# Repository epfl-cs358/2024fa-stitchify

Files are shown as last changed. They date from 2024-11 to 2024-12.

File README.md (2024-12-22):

<!-- ABOUT THE PROJECT -->

## Authors

Wiktoria Rozkosz, Bogdan Cîrje, Imane Raihane, Lorie Xu, Yasmine Hidri, Victor Zablocki

## About The Project
Fueled by curiosity, we worked to create a knitting machine from start to finish. The Knitting Robot is an Arduino-based automation system designed to knit simple fabric patterns such as scarves or scalable fabrics. The project aims to create a functional prototype capable of knitting patterns autonomously.

We based our work on the open source project OpenKnit, and spent a lot of time analysing and researching about how to go about in creating our machine. We obviously didn't have 5-6 years like OpenKnit did, so we had to simplify OpenKnit's design by a lot in order to fit the time frame of 10 weeks.

This is our project prototype in motion:
https://github.com/user-attachments/assets/023492ee-7dcc-4365-b6ac-0f5af49786ec

## Key Features
* **Web Interface**: A web app allows users to upload knitting patterns and customize their projects (e.g., scarves, beanies, or pullovers).
* **Real-Time Feedback**: An LCD screen on the knitting robot shows the progress and alerts users to any errors during operation.
* **Modular Design**: The system is designed to be modular, allowing future expansions and adaptations for more complex knitting patterns.
* **Educational Potential**: This project serves as a tool for teaching robotics, automation, and programming concepts.

## How It Works
The knitting robot operates by using a combination of stepper motors, actuators, and precision-controlled components to manipulate needles and yarn. The process is divided into the following key steps:
### 1. Pattern Upload:
* The user uploads a knitting pattern through the web interface. Typically, this pattern is a custom, text-based file that describes the sequence of knitting actions required for the design.
### 2. Conversion to Instructions:
* The uploaded pattern is then parsed and converted into a series of detailed instructions. These instructions control the robot’s movement and actions, dictating how needles should be raised or lowered.
* The system ensures precise execution of the pattern, coordinating between the needles, yarn feeder, and other actuators.
### 3. Knitting Process:
* Needle Movement: The carriage moves one needle at a time, enabling precise control over which needles are raised. Small servos embedded in the carriage allow the user to select individual needles for activation, ensuring each stitch is placed according to the pattern.
* Yarn Feeding: A large servo controls the yarn feeder, which performs a swiping motion to ensure accurate placement of the yarn on the needles. This motion enhances precision, especially at the endpoints, that require fine control over yarn tension and placement.
* Carriage Movement: The entire carriage is moved by a belt system powered by a NEMA stepper motor, ensuring smooth, coordinated motion across the entire width of the knitting surface.
### 4. Real-Time Feedback:
* LCD Screen: The system features an LCD screen that displays the progress of the knitting process, providing real-time feedback on the pattern's completion.
### 5. User Interaction:
* User Button: A dedicated button allows the user to pause or stop the machine after each row and confirm whether everything is functioning correctly. This button can be used to provide manual intervention if needed, ensuring the process runs smoothly.
### 6. Safety Features:
* Endpoint Switches: At the endpoints of the carriage, there are limit switches that prevent the system from overextending or damaging itself. These switches stop the carriage when it reaches the end of its travel, ensuring safe operation.
This combination of precise needle control, enhanced yarn feeding mechanisms, and real-time monitoring allows the knitting robot to produce high-quality knitting patterns with minimal manual intervention.

## Used Components

### Yarn Types:
- **Heavy Yarn**  
- **Normal Yarn**  
- **Synthetic Yarn** (Optional)

### Key Components:

1. **Needles**:  
   - 500 knitting needles required for the machine.

2. **Motors**:  
   - **8 or more motors**: NEMA 17 or Bipolar 17HS4401 stepper motors.
   - Motors for the following tasks:  
     - 1 motor for each yarn color.  
     - Motors for yarn feeders and moving the rails.
     - 2 motors for moving the beds on the Y-axis.

3. **Connectivity Modules**:  
   - **Wi-Fi Modules** or **Bluetooth Modules** for remote control or data transmission.

4. **Security Sensors**:  
   - **HC-SR04 Ultrasonic Distance Sensor** for clearance monitoring in the working area.

5. **Mechanical Parts**:  
   - **Belts**: 10 x 5-meter belts and their necessary attachments.
   - **Screws, metal beams, belts, and wiring** (provided in stock).

6. **Microcontroller ISP**:  
   - 10 units required, with or without camera integration.

7. **Voltage Converter**:  
   - **8-channel logic-level converter** - CHF 1 each.

8. **Measuring Components**:  
   - **MPU-6050 6 DOF Inertial Measurement Unit** for motion sensing of knitting needles - CHF 5.  
   - **CUI AMT-102-V Rotary Incremental Encoder** (Optional) for measuring needle motion - CHF 21.  
   - **Chihai CHF-GM37-550ABHL Gear Motor with Encoder** for controlling needles precisely - CHF 25.  
   - Additional motors, as needed - CHF 35.

9. **Display and Control**:  
   - **LCD Screen** to show progress and yarn levels.  
   - Yarn levels can be detected by weight sensors or through camera integration.  
   - **Power Supply**: Required for the overall system.  
   - **Control Button** for manual operation and adjustments.

10. **Other Components**:  
    - Additional motors and components for electrical setup.

---

### Additional Information

- **Design Files**:  
  All parts for 3D printing are available on our GitHub repository. Files for laser cutting (wood and plexiglass) are also included.

- **Materials Provided**:  
  Screws, metal beams, belts, and wiring are available for the assembly.

---

## Estimated Cost
The estimated cost of the project is around $500, which includes motors, stepper controllers, structural components, and electronics.
---
## Fusion Designs
Below is the very first overall design on Fusion that was created for this project :

After numerous trials and errors, we finally settled on the final prototype Fusion design as seen below, which can also be found in the repository :




## Electrical Designs
Below is the initial design incorporating multiple stepper motors to improve torque, 1 ESP32-CAM for computer vision (which wasn't implemented in our project in the end), the Wemos D1 R32, 16-channel servo controller and the Arduino Uno :
385799670-8f64526a-a05f-4db1-b084-6b4fe1a5de26

Below is the current project's Fritzing sketch :


## Mechanical Designs
 * **Carriage** : 
 * **Aluminium structure** : 
 * **Flatbed** : 
 * **Yarn feeder, slider** : 
 * **Stepper motor and belt pincher** : 


 * **Comb** : First tried a prototype using paper clips to see how it could work, then we made a comb with a hole to allow the addition of a weight.

## Code Implementation
The code implementation included the master-slave different data sharing channels and management, the controller for the stepper motor (slave) and servo motors (master), a WEMOS hosting a webapp that allow communication and the launch of customized patterns, and a file format that was designed to define pattern.

## Program Overview

### Command Parsing & Buffer Management
- Commands control various knitting machine components such as servos, motors, needle movements, and knitting actions.
- The program buffers incoming serial commands and processes them sequentially.

### Movement Control
- Supports servo and motor movement commands (`l`, `r`, `s x`, `n x`) for precise positioning.
- Knitting commands (`kr`, `kl`, `lt x`, `rt x`) manage the machine's movement during the knitting process.
- Supports knitting multiple rows with optional row confirmation (`knit x`, `knits x`, `knitp x`).
- Alternates between knitting rows to complete a full knit.

### LCD Feedback
- Provides real-time feedback via LCD, including status updates like "Knitting done".

### Serial Communication
- Listens for serial commands, handles multiple commands separated by semicolons, and processes them in sequence.
- Communicates with NEMA motors via I2C using the Wire library additional channel for acknowledgments from the slave.

### Synchronization & Delays
- Includes delays to synchronize servo and motor movements, ensuring proper sequencing of actions.

### Multi-command Support
- Supports processing multiple commands in a single input, separated by semicolons, for efficient execution.

### Wemos Integration
- **SPIFFS**: Utilizes the SPIFFS (Serial Peripheral Interface Flash File System) for managing storage and hosting files efficiently on the Wemos device.
- **HTTP Requests**: Sends HTTP requests from the Wemos device to a server, facilitating communication and pattern management.
- **Backend Communication**: Integrates with a Node.js backend to handle pattern requests, ensuring smooth interaction between the React frontend and the Wemos device.

### Wemos to Master Communication
- The **Wemos device** communicates directly with the **master controller**, sending commands and pattern data via **HTTP requests**. This enables the Wemos to relay instructions, such as motor movements or pattern changes, to the master, ensuring seamless control and coordination between the Wemos, the master, and the knitting machine.

### Web Application
- The web application is built using **React** and includes several pages:
  - **Home**

    
  - **Project Overview**
    
  - **Download Pattern**
    
  - **Create Pattern**
    
  - **Contact**
    

- The React frontend communicates with the Wemos device to upload/download patterns and interact with the knitting machine.

- **Backend**: The lightweight server, built with Node.js, handles pattern requests from the React frontend to the Wemos device.
---

## File Breakdown

### `master_with_interpreter`
- Handles command parsing, communication with the slave, and overall program management.

### `slave`
- Receives I2C commands from the master and controls the NEMA motors based on those commands.

## Knitting Machine Control Code

### Supported Commands

#### # Movement Commands
- **`l`**: Move small servos to the left.
- **`r`**: Move small servos to the right.
- **`s x`**: Move the big servo to position `x` (range: 0–180).
- **`s1 x`**: Move small servo 1 to position `x` (range: 0–180).
- **`s2 x`**: Move small servo 2 to position `x` (range: 0–180).
- **`n x`**: Move NEMA motors by `x` steps (positive for forward, negative for reverse).

#### # Basic Knitting Commands
- **`krb`**: Knit a full row to the right (basic).
- **`klb`**: Knit a full row to the left (basic).

#### # Advanced Knitting Commands
- **`krs`**: Knit a full row to the right (switch, wait for confirmation).
- **`kls`**: Knit a full row to the left (switch, wait for confirmation).
- **`krp`**: Knit a full row to the right (pattern, wait for confirmation).
- **`klp`**: Knit a full row to the left (pattern, wait for confirmation).

#### # Needle Positioning Commands
- **`fl`**: Move to the first needle on the left from the switch point.
- **`fr`**: Move to the first needle on the right from the switch point.
- **`al`**: Move after the first needle on the left (continue from the last step to the end).
- **`ar`**: Move after the first needle on the right (continue from the last step to the end).

#### # Needle Management Commands
- **`lt x`**: Take `x` needles to the left (raise needles up).
- **`rt x`**: Take `x` needles to the right (raise needles up).
- **`ls x`**: Skip `x` needles to the left (lower needles down).
- **`rs x`**: Skip `x` needles to the right (lower needles down).

#### # Row Knitting Commands
- **`knit x`**: Knit `x` rows (a right and left movement together count as one row).
- **`knits x`**: Knit `x` rows (step-by-step, waiting for confirmation after each row).
- **`knitp x`**: Knit `x` rows (pause after each row, wait for confirmation to continue).

### Examples
1. Move small servo 1 to position 90:
   ```
   s1 90
   ```
2. Knit 5 rows with step-by-step confirmation:
   ```
   knits 5
   ```
3. Take 10 needles to the right:
   ```
   rt 10
   ```
4. Knit a full row to the left with pattern confirmation:
   ```
   klp
   ```

### Notes
- For all servo commands, ensure that the position values (`x`) are within the valid range of 0–180.
- For `knit`, `knits`, and `knitp` commands, the row count includes both right and left movements as a single row.
- Confirmations for step (`knits`) and pattern (`knitp`) commands must be manually provided before proceeding to the next step.

<!-- Issues -->
## Issues and Decisions Taken
Some of the issues we encountered during our prototyping and the decisions taken in regards to them are described below :

**1. Circular or flatbed design** : Originally, the circular design was preferred for its simplicity and the numerous available models on the market could've provided valuable insights and support for our project. However, we finally decided to work on the flatbed design, as it offered a more interesting and intricate mechanism and was overall more challenging.

**2. Number of needles, beds, lenghts etc** : There was a lot of discussion about how big the first prototype needed to be. The option of adding a second bed was pushed back to the second prototype and we sadly didn't have enough time to implement it in the end. We decided to use 23 needles, the ones given by the MIT teaching team, for the first prototype as the ones sponsored were too different to the project OpenKnit we were basing our machine on and would necessitate more work on the design part.

**3. Servos and stepper motors** : In the earliest design, there were 4 servos as we needed two carriages on both sides of the bed (double bed) and more stepperes to improve torque. In the end, we decided on reducing those numbers to two servos (not counting the one for the yarn feeder) and one stepper. Since the number of servos was lowered, the 16-channel servo controller wasn't needed anymore.

**4. Yarn feeder** : Originally, the yarn feeder could roll on the top bar, pushed by the carriage linked to the stepper motor on the side. This design was to allow multiple yarn feeders to coexist, thus introducing the ability to use multiple yarns for the same knit. It was however put aside as the tension created by the stepper on the side generated too much friction and the movement wasn't smooth enough. We decided to put the yarn feeder directly linked to the carriage along with the servo motor that could control its angles.

**5. Yarn feeder slider** : At the beginning, it was just supposed to slide on the top aluminium bar. We added two bearings to improve the smoothness of the movement and reduce the irregularities of the sliding. The bearings were on top and bottom of the bar at first, then moved to the two sides to fix the movement area and not allow any liberties to the slider. However, after the last changes made to the yarn feeder, the slider wasn't needed anymore (but can be an interesting upgrade in case of further work on the project).

**6. Carriage** : The carriage was, at first, designed to roll on a bar at the end of the bed. We however decided to change its support, as it generated too much movement and wasn't stable enough. The overall design was also reworked to be lighter both in weight and material, reducing the printing time. We decided to have metal rods directly fixed above the carriage with marble bearings inside to allow smooth movement at all times.

**7. Carriage rods support** : Initially, they were to be fixed on the bed using a 3D printed piece but the piece took up too much space and hindered the movement of the carriage. We finally decided on using MDF triangle panels fixed on the aluminium bars to hold up the rods, pulley and stepper.

**8. Stepper motor** : It was first designed to be fixed on the side bars, allowing movement of the carriage, which will push the first design of the yarn feeder. However, as it was far from where the heaviest build was (the carriage), it had difficulties to push everything and the belt would twist. We moved the stepper motor down, in between the two bars that supported the carriage, and fixed everything (metal rods, stepper and pulley) on a MDF side panel after careful computations on the carriage's position.

**9. Switches** : They were originally also supposed to be fixed on the side panels, but further consideration showed they would hinder the pulley and stepper motor supports. In the end, they are fixed on the bed.

**10. ESP32-CAM vs Wemos D1 R32 vs Arduino Uno** : We originally wanted to use the ESP32-CAM as it had built-in wifi connectivity and would allow wireless communication with the main Arduino Uno, in addition to its small size. However, we discovered that in the way we wanted to use it, there would only be a very small number of usable pins, which wasn't enough at all. We decided to look into the Wemos R32, which also had built-in wifi and looked a lot like an Arduino Uno. But there was a lot of pins adaptation issues as the Wemos uses a different pin naming pattern. In the end, we just decided to use an additional Arduino Uno for prototype 1 and managed to use the Wemos R1 D32 for connectivity with the webapp.

## Possible Future Enhancements

While the current prototype of the knitting machine is functional, there are several possible improvements and upgrades that could be explored in future iterations of the project:

- **Automated Yarn Feeder**: Future versions could include a more sophisticated yarn feeder capable of handling multiple yarns simultaneously, allowing for more complex and varied knitting patterns.

- **Second Bed**: The design for a second bed could be revisited to enable multi-layer knitting, enhancing the machine’s capabilities for more advanced knitting techniques.

- **Computer Vision Implementation**: The integration of an ESP32-CAM or similar vision system could enable advanced control features, such as automated pattern recognition or more precise needle positioning through real-time image processing.

- **Improved Web Interface**: The web application could be enhanced to make pattern creation more intuitive, offer real-time feedback during the knitting process, and improve communication with the machine. Features could include drag-and-drop pattern design, live status updates, and automatic pattern generation.

## Final Prototype 
396272513-12e6db7e-80a0-43ea-b348-9f53fb4e29a5
396790100-0d9a8779-574e-494d-af5e-7b810effc59a
396790045-effc61c9-1916-40eb-b391-8df3ec1e6962

![3](https://github.com/user-attachments/assets/c578a88d-b044-4fa2-922c-78
04e1432b35)

## Videos

https://github.com/user-attachments/assets/3eb57e5a-5048-47de-83a3-ed956dd14b73

https://github.com/user-attachments/assets/bcacb11a-032e-467d-a626-ce686c609b23

https://github.com/user-attachments/assets/3af8717c-1401-49d2-a916-b31e1aa85cad

https://github.com/user-attachments/assets/558318ca-72b1-469a-9f6d-11a843931621

https://github.com/user-attachments/assets/9c9bbe95-ea37-4b26-9b40-f3b2f7e56fe6

## Real-World Applications
The knitting robot could be used in textile prototyping, allowing designers to test new patterns and fabric types quickly. It could also be useful for small-scale textile production in custom-made fashion.

## Conclusion

The Knitting Robot is a unique blend of robotics, software, and knitting technology. By automating the knitting process, this project aims to make knitting more accessible, efficient, and customizable.

## License

Distributed under the MIT License. See LICENSE.txt for more information.

<p align="right">(<a href="#readme-top">back to top</a>)</p>

<!-- MARKDOWN LINKS & IMAGES -->
<!-- https://www.markdownguide.org/basic-syntax/#reference-style-links -->
[contributors-shield]: https://img.shields.io/badge/CONTRIBUTORS-6-brightgreen?style=for-the-badge
[contributors-url]: https://github.com/epfl-cs358/2024sp-exoskeleton/graphs/contributors
[license-shield]: https://img.shields.io/badge/LICENSE-MIT-brightyellow?style=for-the-badge
[license-url]: https://github.com/epfl-cs358/2024sp-exoskeleton/blob/main/LICENSE

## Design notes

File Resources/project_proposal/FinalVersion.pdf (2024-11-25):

# CS-358 Making Intelligent Things

## Knitting Robot Project Proposal

## Group Members:

Wiktoria Rozkosz, Bogdan Cˆırje, Imane Raihane, Lorie Xu, Yasmine Hidri, Victor Zablocki EPFL, Lausanne, Switzerland

## Contents

1 Introduction | 3
2 User Stories | 4
3 Product Management | 5
4 Software | 5
5 Bill of Materials | 6
6 Risk Management | 8
7 Encountered Problems | 10
8 Milestones | 10
9 Gantt Chart | 11
10 Electronics and Components | 12
11 CAD designs and dimentions | 13
12 Conclusion | 14

## 1 Introduction

### 1.1 High-Level Description of the Project

The main aim of this project is the development of a Knitting Robot capable of knitting simple patches. The robot will consist of an Arduino-based system that controls actuators to manipulate knitting needles (or hooks), allowing it to produce knitted fabrics autonomously. The final result is expected to be a functional prototype that demonstrates the ability to knit given patterns, such as scarves or scalable fabrics. Further, the project can be extended to more complex knitting patterns with further development.

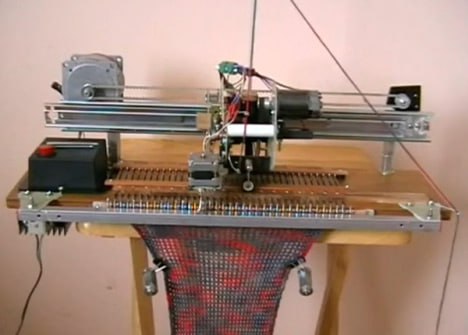
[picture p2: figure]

Figure 1: Existing design of a single axis knitting robot

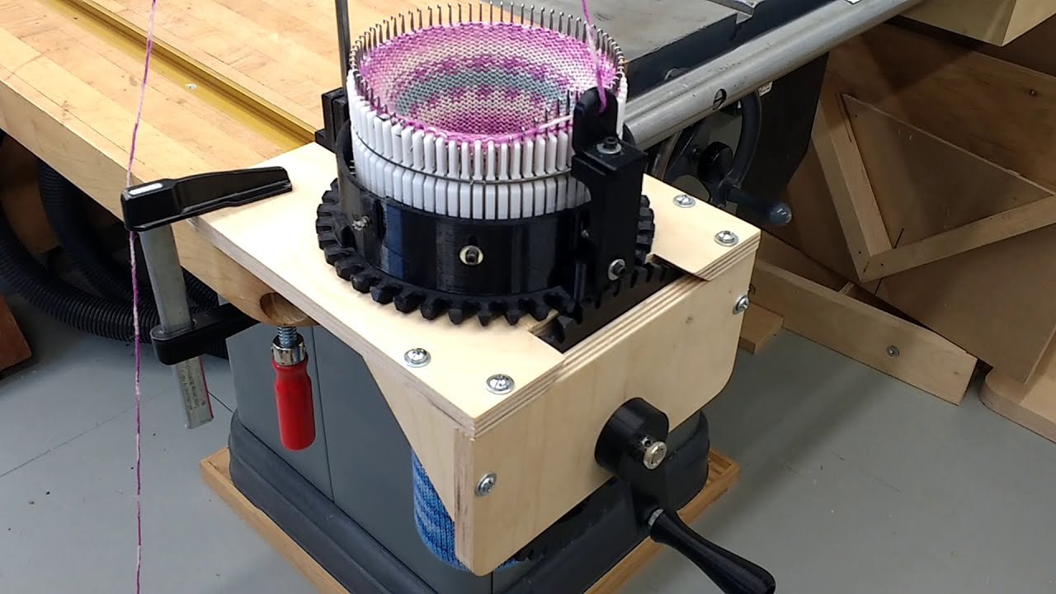
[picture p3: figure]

Figure 2: Round knitting machine. Creating round pattern can also be done by combinating two moving beds of needles.

### 1.2 Related Projects and Resources

Our project is not the first initiative in the realm of automated knitting. Several existing projects and companies have made significant steps in this field, which can serve as inspiration and points of reference for our development:

- OpenKnit Project: An open-source initiative that developed a digital knitting machine (http: //openknit.org/). The project has the benefit of providing good insights into mechanical designs and control systems for knitting automation.
- Kniterate: A commercial digital knitting machine (https://www.kniterate.com/) created by OpenKnit developer, that automates knitting with computer-controlled patterns. While it’s a more advanced system, studying its functionality can inspire potential future features for the project.
- Hand-Cranked Knitting Machines: Designs of traditional knitting machines (e.g. Brother KH series machines) provide foundational knowledge on the mechanics of knitting that can be adapted for automation.
- Arduino Knitting Machine Conversion: Projects where hobbyist have converted manual knitting machines into automated ones using Arduino microcontrollers (https://youtu.be/-AjIKjxDDHE). (https://youtu.be/-AjIKjxDDHE)
- Knitify: Knitify is a notable startup that focuses on automating knitting processes using an innovative approach. Their platform allows users to create and customize patterns digitally, which are then executed by their knitting machines. This project exemplifies how technology can enhance traditional knitting and offers insights into user interface design and pattern generation.

These projects offer mechanical designs, control algorithms, and software that can be referenced and adapted for this project. Their strategies and resolved challenges can be studied to implement our one efficient solution of knitting automation.

## 2 User Stories

- Hobbyist Knitter: As a hobbyist knitter, I want a device that can knit simple patterns automatically so that I can produce scarves and fabrics without spending hours of manual labor.
- Educational Tool: As a prestigious teacher in robotics and automation, I want a demonstration project that showcases the integration of mechanical design, electronics, and software to inspire students about the possibilities of engineering.
- EPFL Demonstrations: As a member of the EPFL IC public relations team, I want a compelling demo that can attract prospective students by showcasing an innovative project combining computer science and mechanical engineering.
- Business Owner: As an owner of a knitting business, I find it useful to explore new solutions in hope of upgrading our factories.
- Future Developers: As a developer interested in advancing knitting automation, I want a modular and open-source project that I can build upon to create more complex knitting patterns or improve efficiency.

## 3 Product Management

From a long-term perspective, this project has the potential to evolve in several ways:

- Educational Kits: The Knitting Robot can be developed into an educational kit for teaching robotics, programming, and automation concepts in schools and universities.
- Open-Source Platform: By making the design and software open-source, we can create a community of developers and makers who contribute to improving and expanding the project’s capabilities.
- Basis for Startups: With further development, the project could lead to the creation of affordable, consumer-friendly knitting machines, filling a niche in the crafting and DIY market.
- Future Course Projects: The mechanical and software components can be reused or expanded upon in future CS-358 projects, allowing students to work on pattern recognition, advanced motion control, or integration with computer vision for pattern customization.

## 4 Software

The software for the knitting robot will center around a web app that serves as the main interface for users to interact with the machine. Through the app, users can upload knitting patterns, select different project styles, and customize settings. The app will allow for versatile choices, such as knitting a scarf, beanie, and hopefully a pullover, with adjustable parameters like size, color, and patterns.

Inspired by the AYAB project (https://www.ayab-knitting.com/) , the knitting robot will accept pattern formats such as bitmap images or text files. The software will digitize these patterns by interpreting each pixel as a specific stitch, enabling the creation of different textures or patterns. The robot will then convert the digital designs into precise row-by-row instructions for the needles.

The knitting robot will have an LCD screen to provide real-time feedback on the knitting process. It will display essential information, such as the progress of the current project, the number of completed rows, and any detected errors. If an issue occurs, such as yarn tension problems or motor stalls, the screen will show an alert, allowing users to pause the machine and resolve the problem before continuing.

## 5 Bill of Materials

This section provides a detailed breakdown of the components required for the Knitting Robot project, along with reasons for their inclusion and links for sourcing.

- In order to test different patterns and produce more complex items, we need differently colored and weighted materials for knitting, e.g., special heavier yarn.
- Switch Sensors: We will use switch sensors instead of the initially planned ultrasonic sensors, which may not perform as expected (e.g., detecting unintended movement from other components, such as yarn). These sensors will act as ”end stops” for the carriage to prevent it from moving beyond its intended range. This is an implementation of a safe-to-fault default.
- USB Isolator: For additional safety, a USB isolator and a camera will be used to monitor operations. The USB isolator will capture any energy spikes that may result from the operation of the NEMA motors, and the camera will allow both the user and us to observe any anomalies during the machine’s operation.
- Stepper Motors and Motor Drivers: Stepper motors will provide precise movements for the knitting machine’s needle beds and carriage. The motor drivers, including A4988 drivers, will control the motors, and it is crucial to adhere to safety protocols due to the associated risks.
- CNC Shield: To facilitate a safer and simpler electronics setup, a CNC shield has been provided for use with the NEMA 17 stepper motors and A4988 motor drivers.
- Rotation Sensor: Initially, a rotation sensor similar to the one used in the OpenKnit project was chosen. If this sensor proves unsuitable, we will switch to an AS5600 rotation sensor for enhanced accuracy.
- Skateboard Ball Bearings: By reducing friction, these bearings will ensure smooth movement for all mechanical parts of the machine. We plan to use six skateboard bearings: two on each flatbed and two in the carriage.
- SG90 Servo Motors: We will initially use smaller SG90 servos for specific parts of the carriage to select needle positions and manage yarn feeders.
- Multiplexer: We will use a multiplexer to incorporate all the elements using just one Arduino and Wemos.
- Voltage Converter: Since our design integrates 12V stepper motors and 5/6V servos, a voltage converter is required.
- LCD Screen: This will provide real-time feedback to the user.
- ESP32 CAM: The ESP32 CAM will provide camera functionality and Wi-Fi capabilities for wireless communication, allowing for remote monitoring and control. An FTDI USB-to-serial converter will facilitate communication between the ESP32 CAM and the computer.
- MPU-6050 (IMU): This sensor will help us track the carriage’s movements, making it easier to control and stabilize.
- Aluminum Bar: This bar will serve as a base for securely mounting all components.

Total Estimated Cost: 239 CHF

Material | Quantity | Price (CHF) | Links
Normal yarn (50g/135m) | 4 | 1.95 (total: 7.8) | Ecru: Click here (https://www.manor.ch/fr/p/p0-11548417) Rose: Click here (https://www.manor.ch/fr/p/p0-11548407) Bleu-Clair: Click here (https://www.manor.ch/fr/p/p0-11548421) Rouge: Click here (https://www.manor.ch/fr/p/p0-11548406) Lilas: Click here (https://www.manor.ch/fr/p/p0-11548420)
Needles | 1 | 50 | Click here (https://steiger-textil.ch/project/antares-3-130/?lang=fr)
HC-SR04 ultrasonic sensor | 2 | 2 (total: 4) | In stock
Microcontroller ESP32-CAM | 3 | 4 (total: 12) | In stock
FTDI USB-to-serial | 3 | 2 (total: 6) | In stock
Arduino Uno | 1 | 5 | In stock
Nema motor + driver (17HS4401 + A4988) | 3 | 15 (total: 45) | In stock
Servo DMS15 (Needle Chooser) | 4 | 5 (total: 20) | In stock
Servo DMS15 (Yarn Feeder) | 1 | 5 | In stock
LCD screen | 1 | 6.20 | Click here (https://www.digitec.ch/fr/s1/product/joy-it-arduino-display-16x2-lcd-module-vert-accessoires-pour-carte-de-developpement-15779686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)
Skateboard ball bearing | 8 | 1 (total: 8) | In stock
PCA9685 16-channel PWM Multiplexer | 1 | 12 | In stock
Belts (2 meters) | 1 | 2 | In stock
Bourns PEC11R-4020K-S0012 | 2 | 1.75 (total: 3.50) | Click here (https://www.mouser.ch/ProductDetail/652-PEC11R-4215K-S24)
8-channel logic-level converter | 2 | 1 (total: 2) | In stock
USB isolator | 1 | 15 | In stock
Aluminium bar | 3 meters | — | From mechanical shop
Power supply 120 W | 1 | 29.70 | Click here (https://www.digitec.ch/fr/s1/product/intertech-unite-dalimentation-externe-connexion-externe-120-w-alimentation-pc-13914783)
LM2596 buck converter | 1 | 4.45 | Click here (https://www.mouser.ch/ProductDetail/426-DFR0379)
MPU-6050 (IMU) | 1 | 5 | In stock
Power connector | 1 | 0.653 | Click here (https://www.mouser.ch/ProductDetail/490-PJ-102B)

Table 1: Bill of Materials for the Knitting Robot Project

## 6 Risk Management

In this section, we identify the potential risks that could affect the successful completion of the Knitting Robot project and outline strategies to mitigate them.

- Risk 1: Hardware Component Failure

– Description: Components such as the Arduino microcontroller, motors, or sensors might malfunction or be faulty.

– Impact: High – A malfunctioning component could prevent the knitting robot from functioning correctly, causing delays.

– Probability: Medium – While unlikely, it is possible for hardware components to fail, particularly if they are not tested thoroughly.

– Mitigation: Thorough testing of individual components before integration will be carried out. Backup components will be bought in advance to ensure quick replacement if needed.

- Risk 2: Integration of Software and Hardware

– Description: The integration of the Arduino programming with mechanical components might lead to unforeseen issues, such as synchronization failures or inaccurate knitting patterns.

– Impact: Medium – Inconsistent communication between software and hardware could result in a malfunctioning prototype or poor performance.

– Probability: Medium – Software bugs or mechanical misalignment could occur during integration.
– Mitigation: Use step-by-step testing during development to ensure each subsystem (e.g., needle control, motor movement) works independently before integrating them. Unit testing of code and simulations of movements will be performed to catch errors early in the process.
- Risk 3: Budget Overrun

– Description: The estimated costs may exceed the available budget due to unexpected component requirements or additional parts needed for repairs.

– Impact: Medium – Exceeding the budget could limit the ability to acquire necessary parts and delay completion.

– Probability: Medium – The current cost estimate leaves ample room for unforeseen expenses, but unexpected costs could still arise.

– Mitigation: We will adhere closely to the budget estimate, only purchasing additional components if absolutely necessary. Additionaly we will try to accuire components from different suppliers for best price possible.

- Risk 4: Difficulty in Achieving Desired Knitting Accuracy

– Description: The knitting robot may not achieve the level of precision required to create high-quality fabrics, especially for more complex knitting patterns.

– Impact: High – Inaccurate knitting could lead to poor-quality outputs or failure to meet project goals.

– Probability: Medium – Ensuring consistent and precise needle movement is technically challenging.

– Mitigation: Focus initially on achieving accurate knitting of simple patterns before scaling to more complex designs. Best precision motor controls will be used to increase precision.

- Risk 5 Sustainability and Environmental Risks

– Description: The project could lead to environmental impact through the use of non-recyclable materials or energy consumption during operation.

– Impact: Moderate to High – The use of non-recyclable materials could contribute to environmental degradation, while high energy consumption could increase the carbon footprint, potentially damaging the project’s sustainability goals and public perception.

– Probability: Medium – While it is feasible to use sustainable materials, constraints like cost or availability may lead to compromises on eco-friendliness.

– Mitigation: The design will prioritize the use of sustainable materials wherever possible, such as recyclable or biodegradable components. Additionally, the power requirements of the system will be assessed to minimize energy consumption during operation, and we will explore options for using renewable energy sources.

Effective risk management ensures that potential challenges are anticipated and mitigated, helping the project stay on track and within budget.

## 7 Encountered Problems

During the initial stage of development of the Knitting Robot, we encountered several challenges that have required adjustments to our initial plans:

- Circular Knitting Challenge: We initially aimed to create circular objects, such as beanies, using a single-axis machine. However, we discovered that the current machine design only supports straight-line knitting, which makes it difficult to achieve seamless circular patterns. We are exploring the possibility of modifying the design by combining two beds of needles to simulate a circular motion.
- Affordable Needles: Another issue has been sourcing affordable and appropriate needles for the project. Easily available specialized knitting needles for automation are either too expensive or difficult to find within our budget constraints. To mitigate this, we are considering using fewer needles or opting for wooden alternatives for the prototype phase. We also plan to explore using wood or metal cutting to fabricate custom knitting tools, allowing us to continue development while waiting for the delivery of proper needles.

We are continuing to explore alternative solutions to these problems while ensuring the project stays on track.

## 8 Milestones

Throughout the development of the Knitting Robot project, we have outlined the following key milestones to track progress and ensure that each stage of the project is completed on time:

- Milestone 1: Create a Smaller Prototype with One Bed and Two Yarn Colours The initial milestone involves building a smaller prototype version of the knitting robot that uses one bed of needles and supports knitting with two different yarn colours. This prototype will serve as a proof of concept, allowing us to validate the basic knitting mechanics, including for example yarn manipulation. This milestone also includes testing the integration of the hardware and software components.
- Milestone 2: Build a Larger Version with Two Beds of Needles
In this stage, the design will be expanded to a larger version of the knitting machine featuring two beds of needles, allowing for more complex knitting patterns and increased knitting efficiency. The two beds will make it possible for example to explore the creation of circular patterns, and this milestone will include the testing and improving of the new mechanical setup.
- Milestone 3: Implement a Moving Bed, Add More Yarn Colours, and Create Patterns
The final milestone will involve adding the capability of a moving bed, enabling the machine to knit with multiple yarn colours beyond two, allowing for more complex patterns and designs. The moving bed will allow for a broader range of designs, enhancing the versatility of the knitting robot.

## 9 Gantt Chart

In our proposal, we used a Gantt chart to effectively manage tasks and project timelines. This approach will help us to monitor progress, anticipate potential delays, and provide efficient time management as well as smoother project execution. The Gantt chart serves as a central reference, helping us stay on track with our project goals.

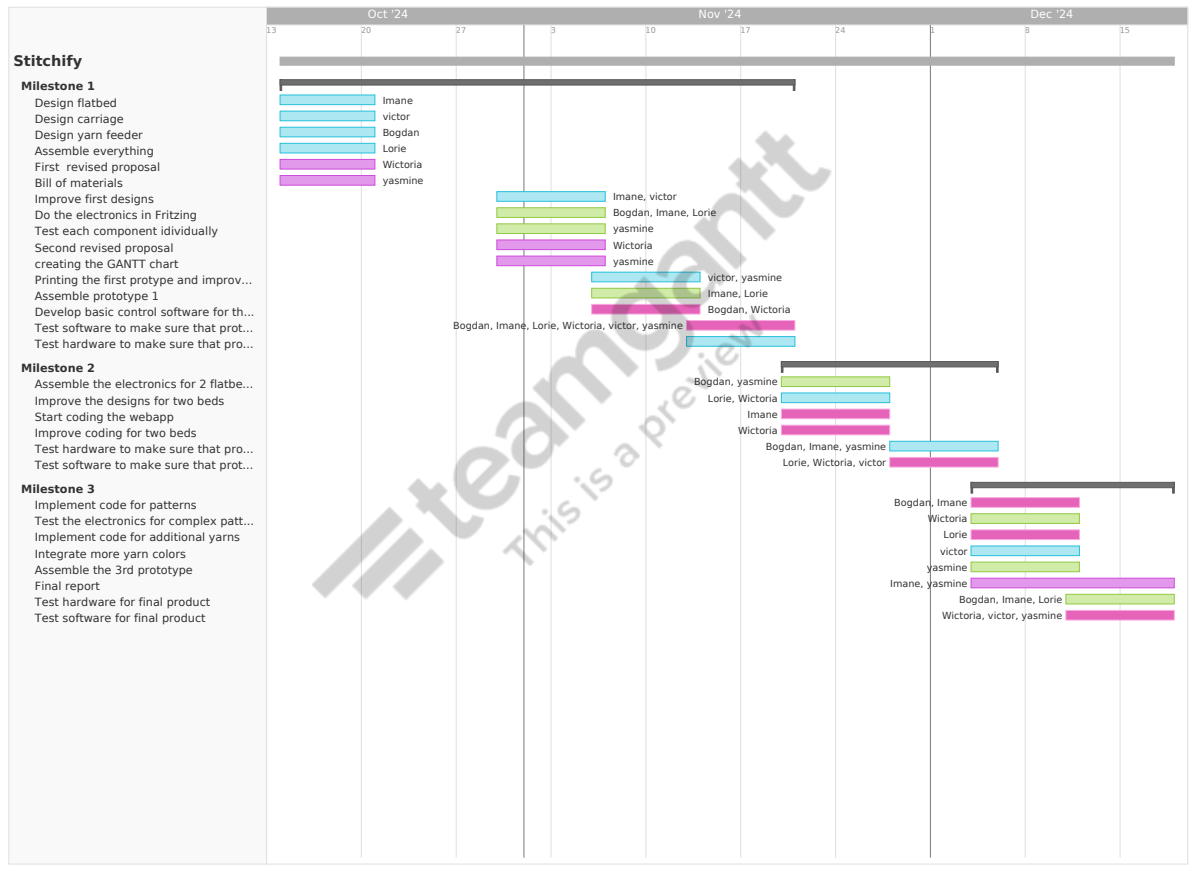
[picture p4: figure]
Oct '24; Nov '24; Dec '24; Stitchify; Milestone 1 Design flatbed Design carriage Design yarn feeder Assemble everything First revised proposal Bill of materials Improve first designs Do the electronics in Fritzing Test each component idividually Second revised proposal creating the GANTT chart; Assemble prototype 1; Test software to make sure that prot... Test hardware to make sure that pro...; Milestone 2; Improve the designs for two beds Start coding the webapp Improve coding for two beds Test hardware to make sure that pro... Test software to make sure that prot...; Milestone 3 Implement code for patterns; Implement code for additional yarns Integrate more yarn colors Assemble the 3rd prototype Final report Test hardware for final product Test software for final product; Imane victor Bogdan Lorie Wictoria yasmine; Imane, victor Bogdan, Imane, Lorie yasmine Wictoria yasmine; victor, yasmine Imane, Lorie Bogdan, Wictoria; Bogdan, yasmine Lorie, Wictoria Imane Wictoria Bogdan, Imane, yasmine Lorie, Wictoria, victor; Bogdan, Imane Wictoria Lorie victor yasmine Imane, yasmine Bogdan, Imane, Lorie Wictoria, victor, yasmine; Powered by TCPDF (www.tcpdf.org)

Printing the first protype and improv...

Develop basic control software for th...

Assemble the electronics for 2 flatbe...

Test the electronics for complex patt...

Bogdan, Imane, Lorie, Wictoria, victor, yasmine

## 10 Electronics and Components

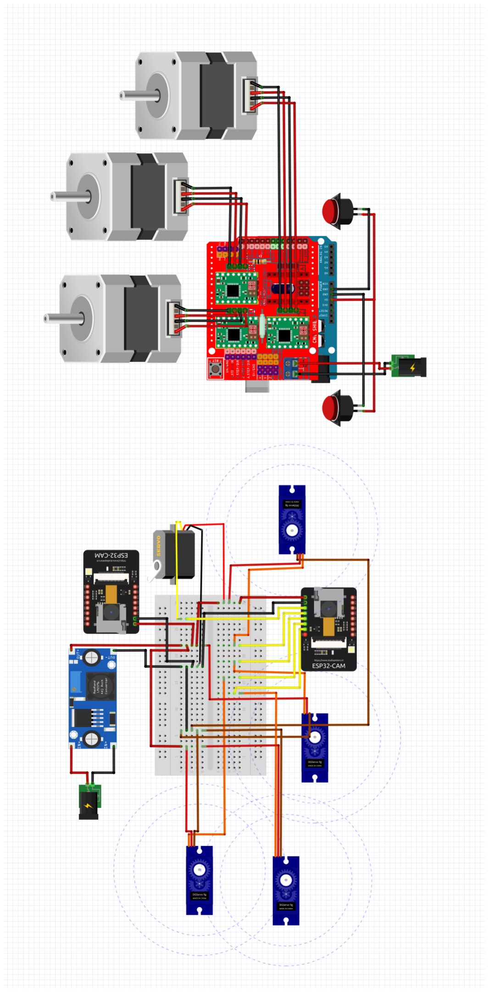
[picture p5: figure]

Figure 3: Electronic assembly

## 11 CAD designs and dimentions

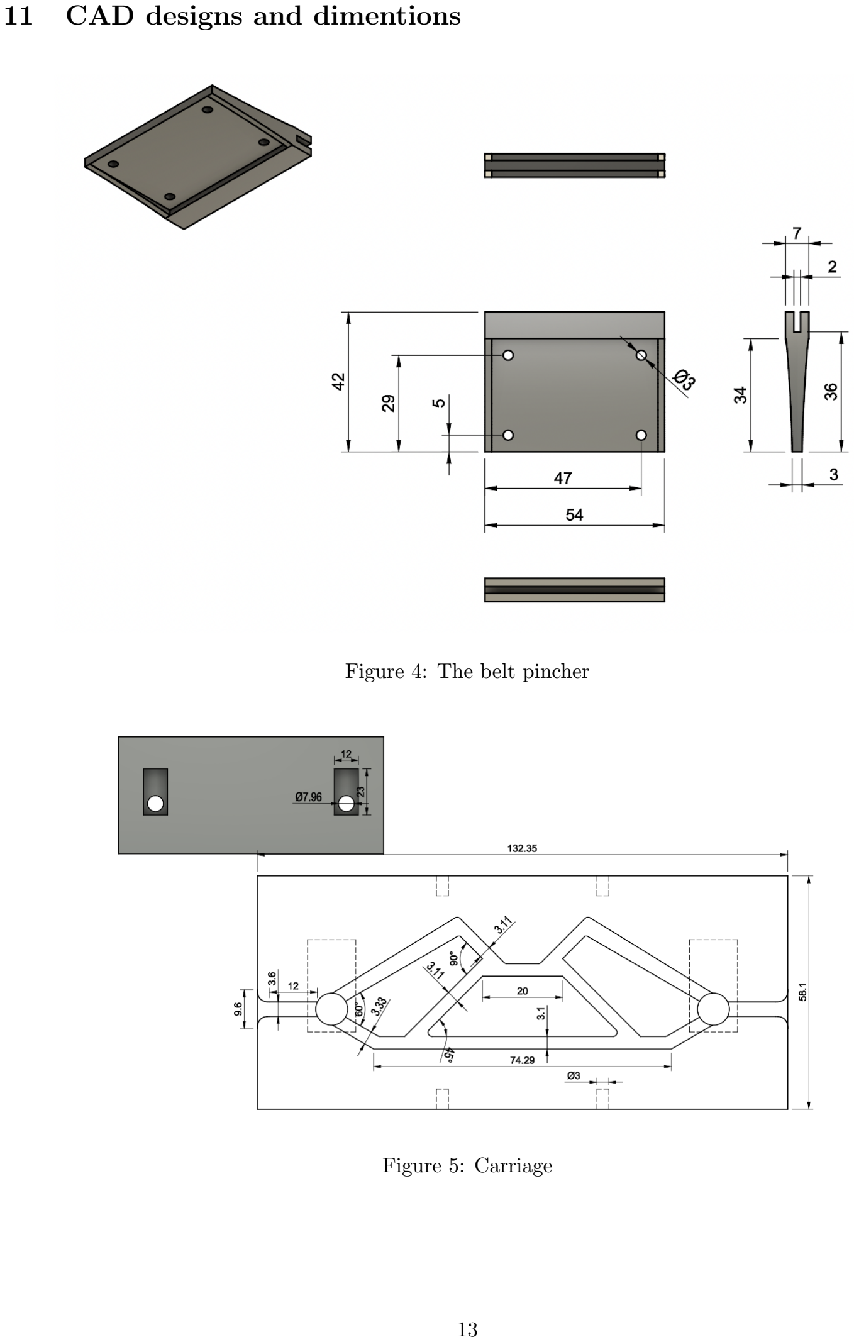
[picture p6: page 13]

Figure 4: The belt pincher

Figure 5: Carriage

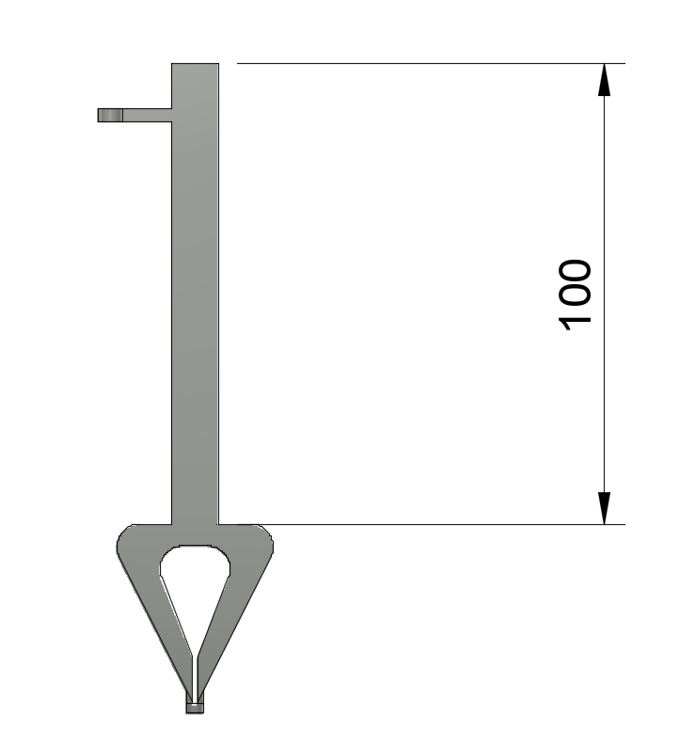
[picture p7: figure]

Figure 6: Yarn Fidder

## 12 Conclusion

The Knitting Robot project aims to automate the traditional craft of knitting. By taking inspiration from existing projects, applying robust risk management, we plan to deliver a fully functional knitting robot prototype that could serve as a foundation for further academic, commercial, and educational purposes.

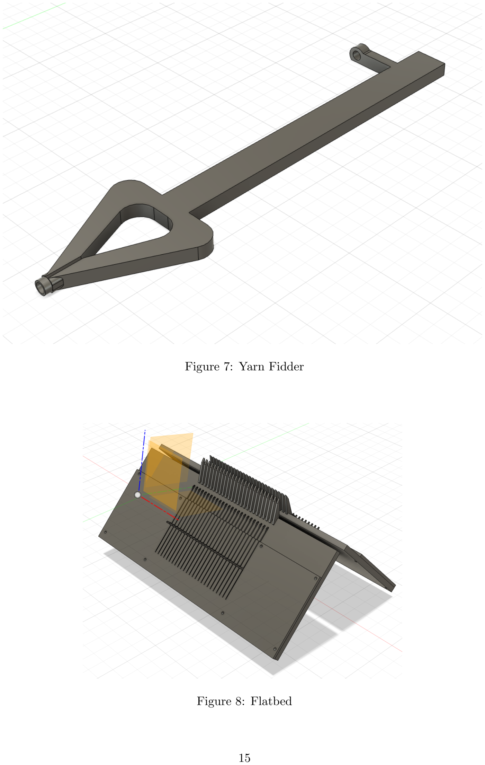
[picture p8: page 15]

Figure 7: Yarn Fidder

Figure 8: Flatbed

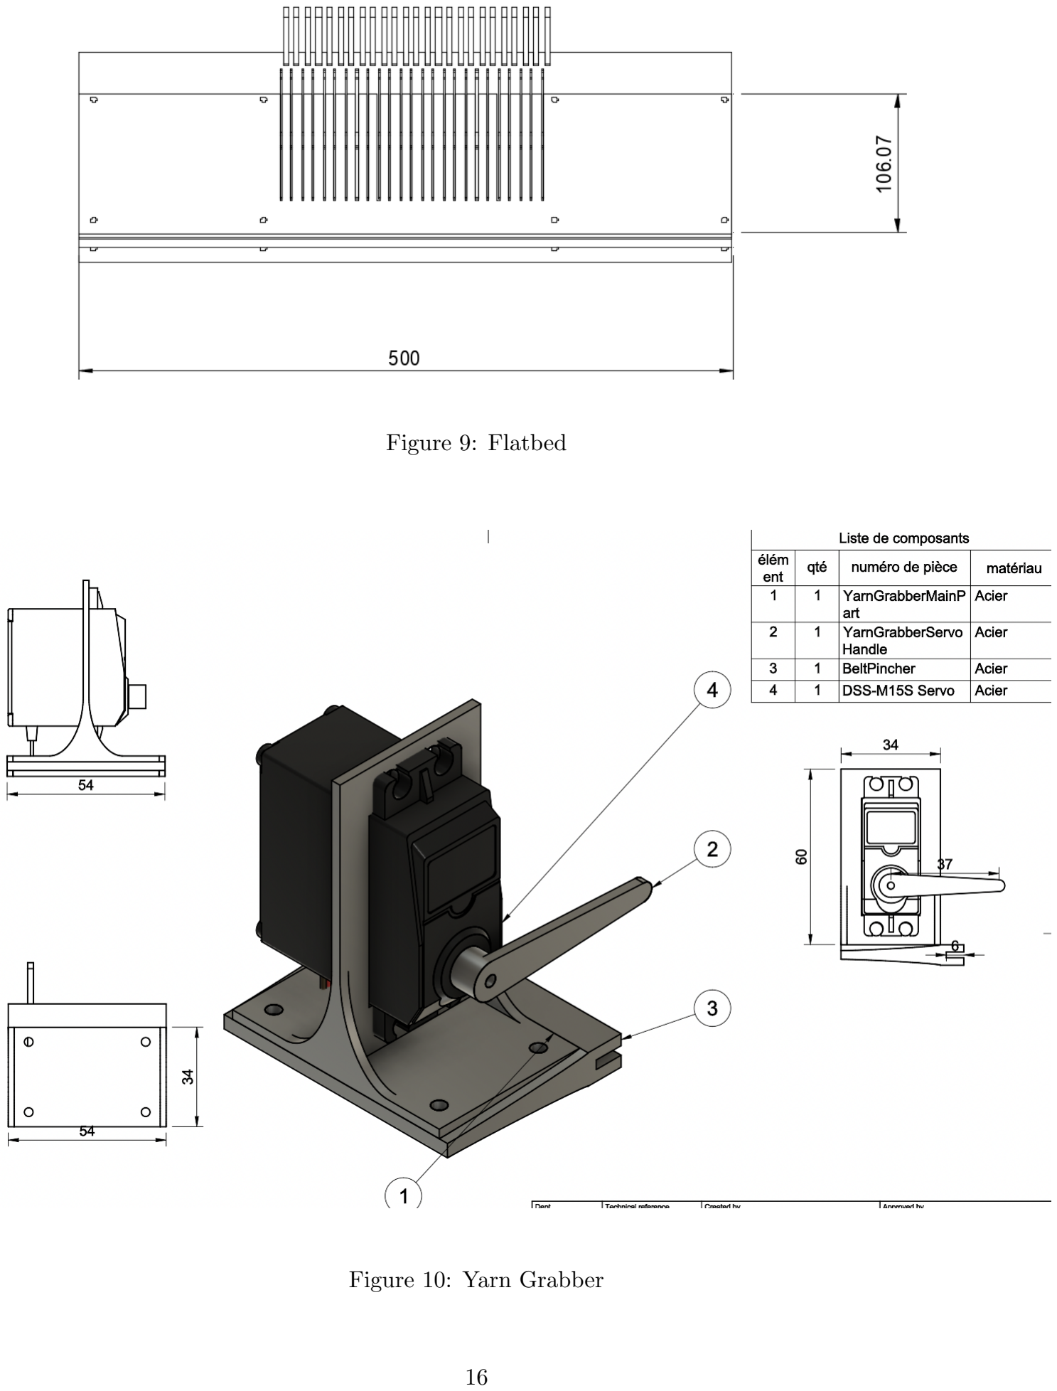
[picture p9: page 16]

Figure 9: Flatbed

Figure 10: Yarn Grabber

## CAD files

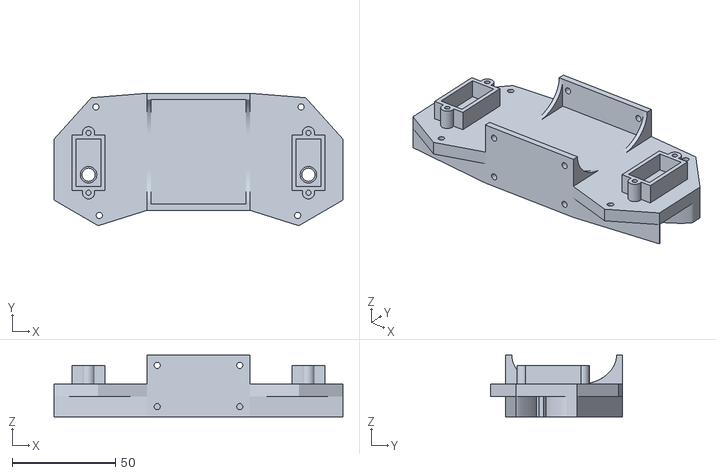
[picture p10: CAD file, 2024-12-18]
Resources/CAD/CarriageMainPart.stl
140.0 x 64.2 x 30.0

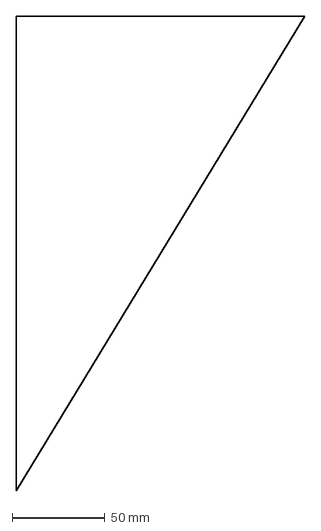
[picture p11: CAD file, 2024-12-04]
Laser Cut/Cotes.dxf
155.0 x 255.0 mm

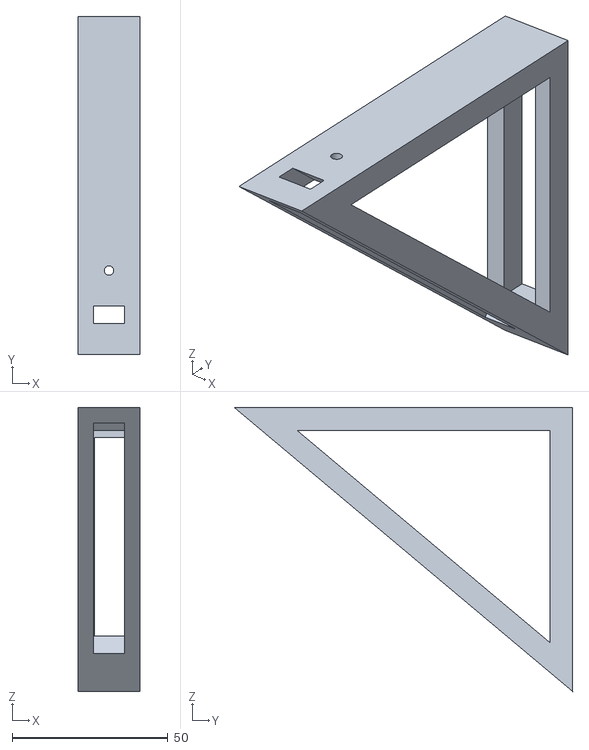
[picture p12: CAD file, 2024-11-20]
Resources/3D Files/Bed Holder.stl
20.0 x 108.5 x 91.1

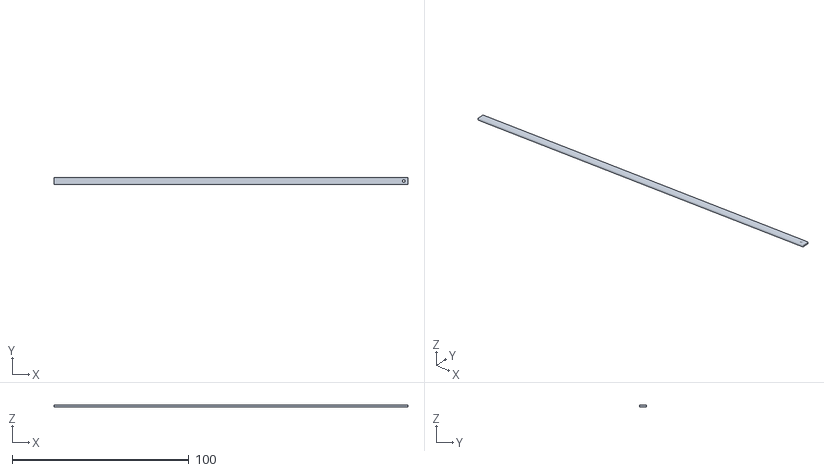
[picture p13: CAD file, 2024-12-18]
Resources/CAD/YarnTensioner.stl
200.0 x 4.00 x 1.00

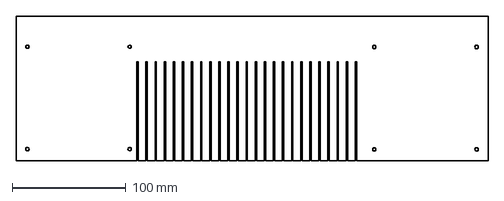
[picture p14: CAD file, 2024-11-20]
Resources/Laser Cut/Bed v2/Overbed v2.dxf
415.0 x 127.0 mm

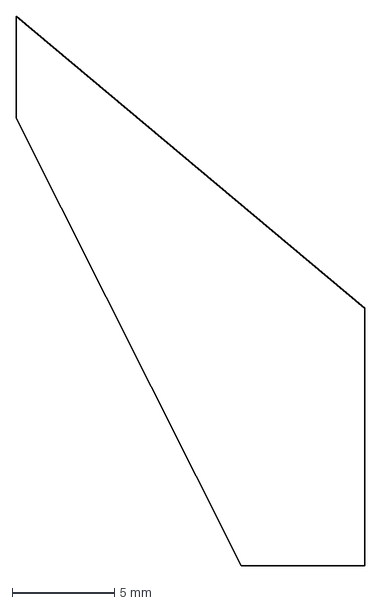
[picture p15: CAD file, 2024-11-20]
Laser Cut/Triangular_Base_linkage_bars.dxf
17.0 x 26.9 mm

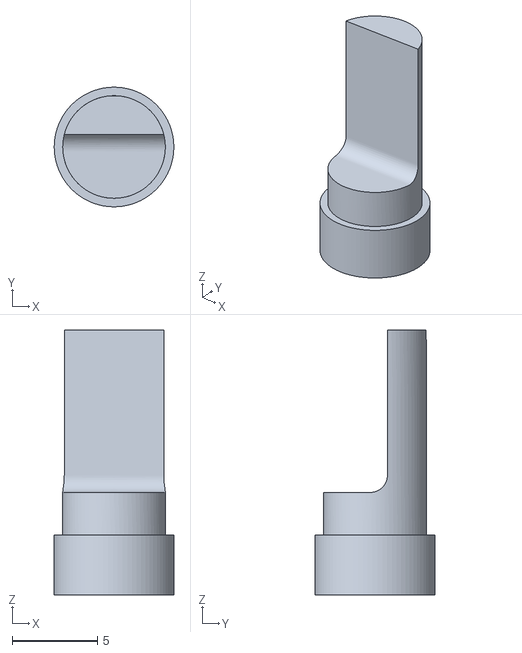
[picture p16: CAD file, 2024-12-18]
Resources/CAD/NeedleChooser v12.stl
7.00 x 7.00 x 15.5

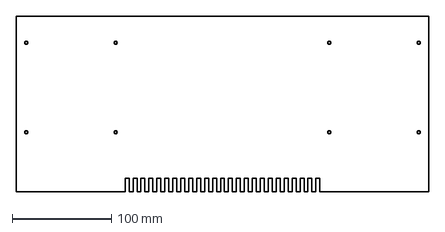
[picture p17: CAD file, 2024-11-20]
Resources/Laser Cut/Bed v2/UnderBed v2.dxf
415.0 x 177.0 mm

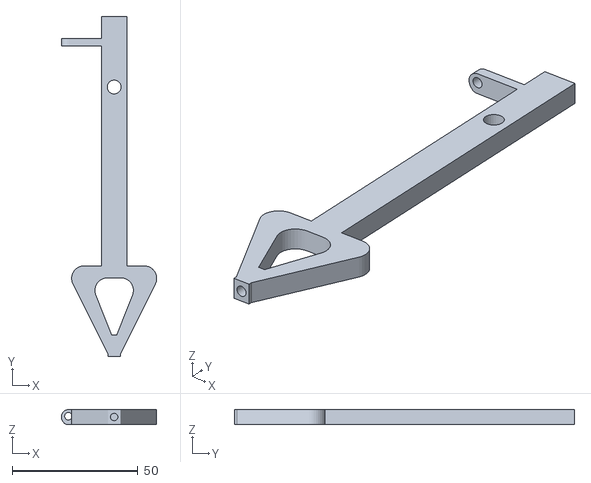
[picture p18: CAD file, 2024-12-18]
Resources/CAD/yarn feeder.stl
37.9 x 135.0 x 6.00

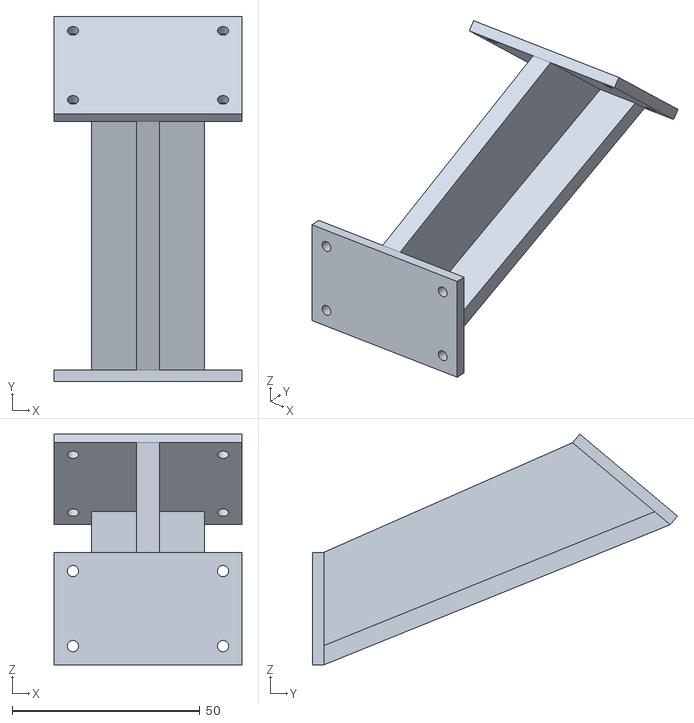
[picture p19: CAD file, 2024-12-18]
Resources/CAD/JointPartCarriage.stl
50.0 x 97.3 x 61.5

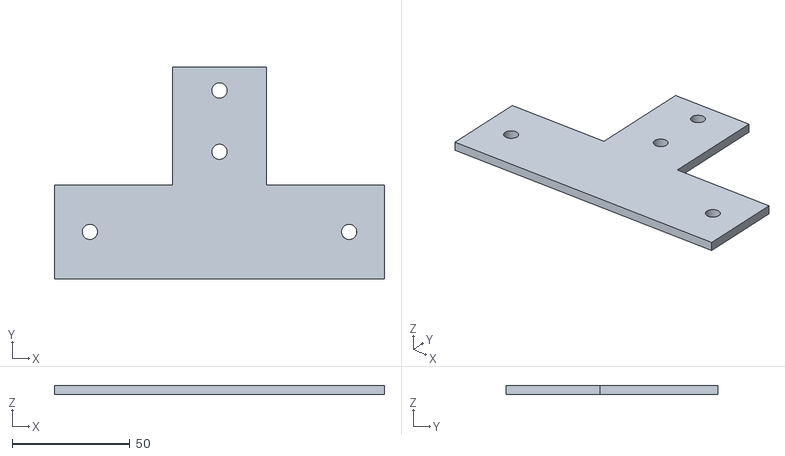
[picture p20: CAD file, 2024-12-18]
Resources/CAD/ALU_Linkage.stl
140.0 x 90.0 x 4.00

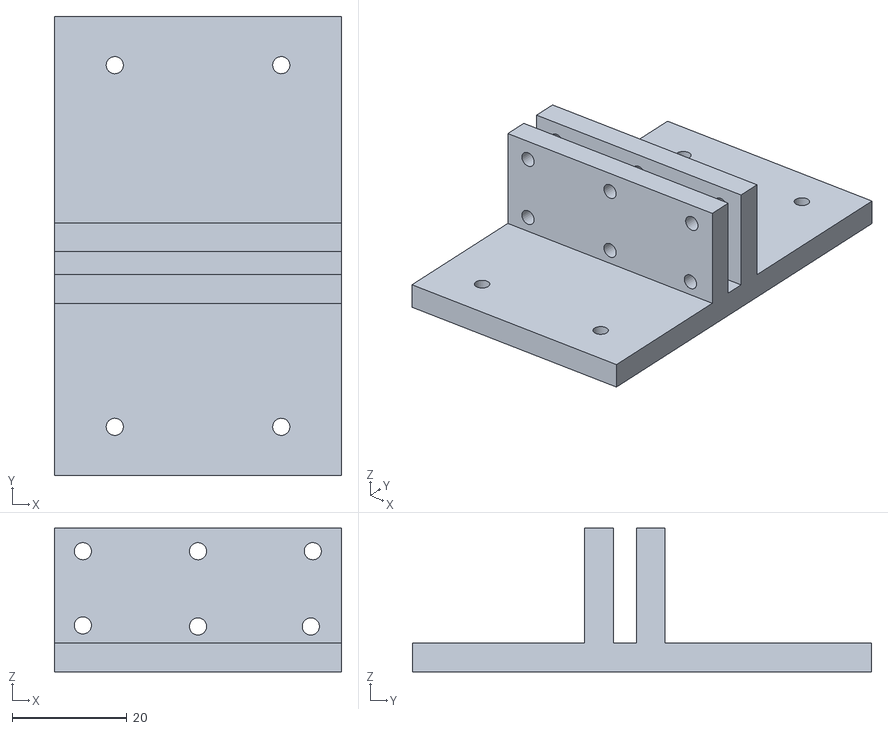
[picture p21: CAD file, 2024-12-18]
Resources/CAD/pincher carriage.stl
50.0 x 80.0 x 25.0

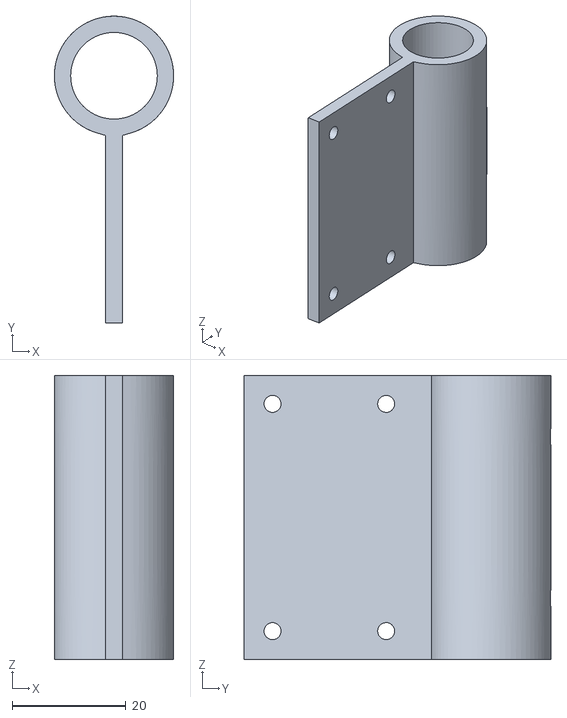
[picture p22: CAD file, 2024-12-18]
Resources/CAD/BarHolder.stl
21.0 x 54.0 x 50.0

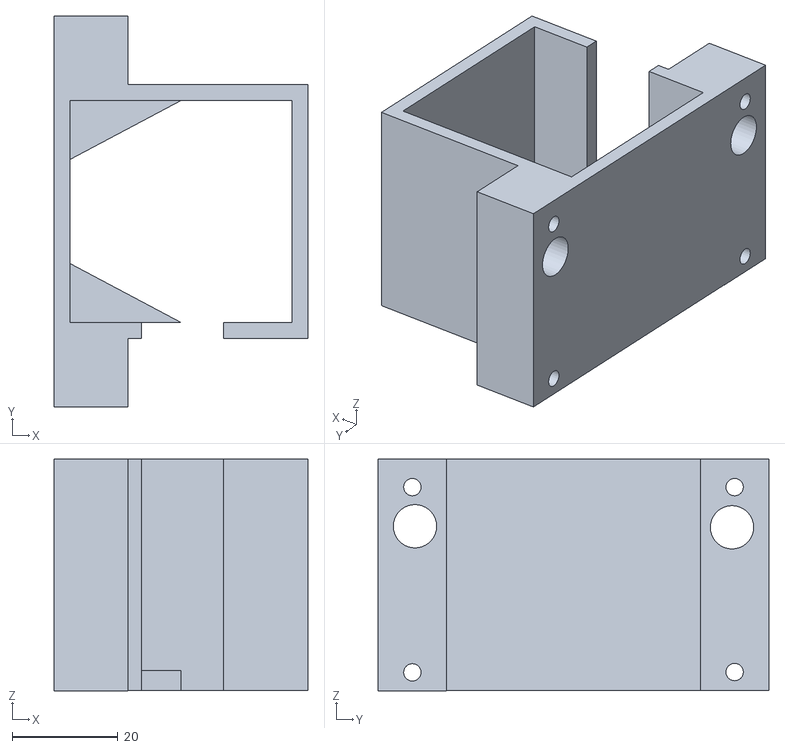
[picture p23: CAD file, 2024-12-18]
Resources/CAD/NemaSupport.stl
48.0 x 74.0 x 43.9

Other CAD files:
Resources/CAD/yarn tensioner second part.stl
Resources/CAD/Pulley.stl
Resources/Laser Cut/Bed v1/UnderBed v1.dxf
Resources/Laser Cut/Bed v1/Triangle Base v1.dxf
Resources/Laser Cut/Bed v1/OverBed v1.dxf

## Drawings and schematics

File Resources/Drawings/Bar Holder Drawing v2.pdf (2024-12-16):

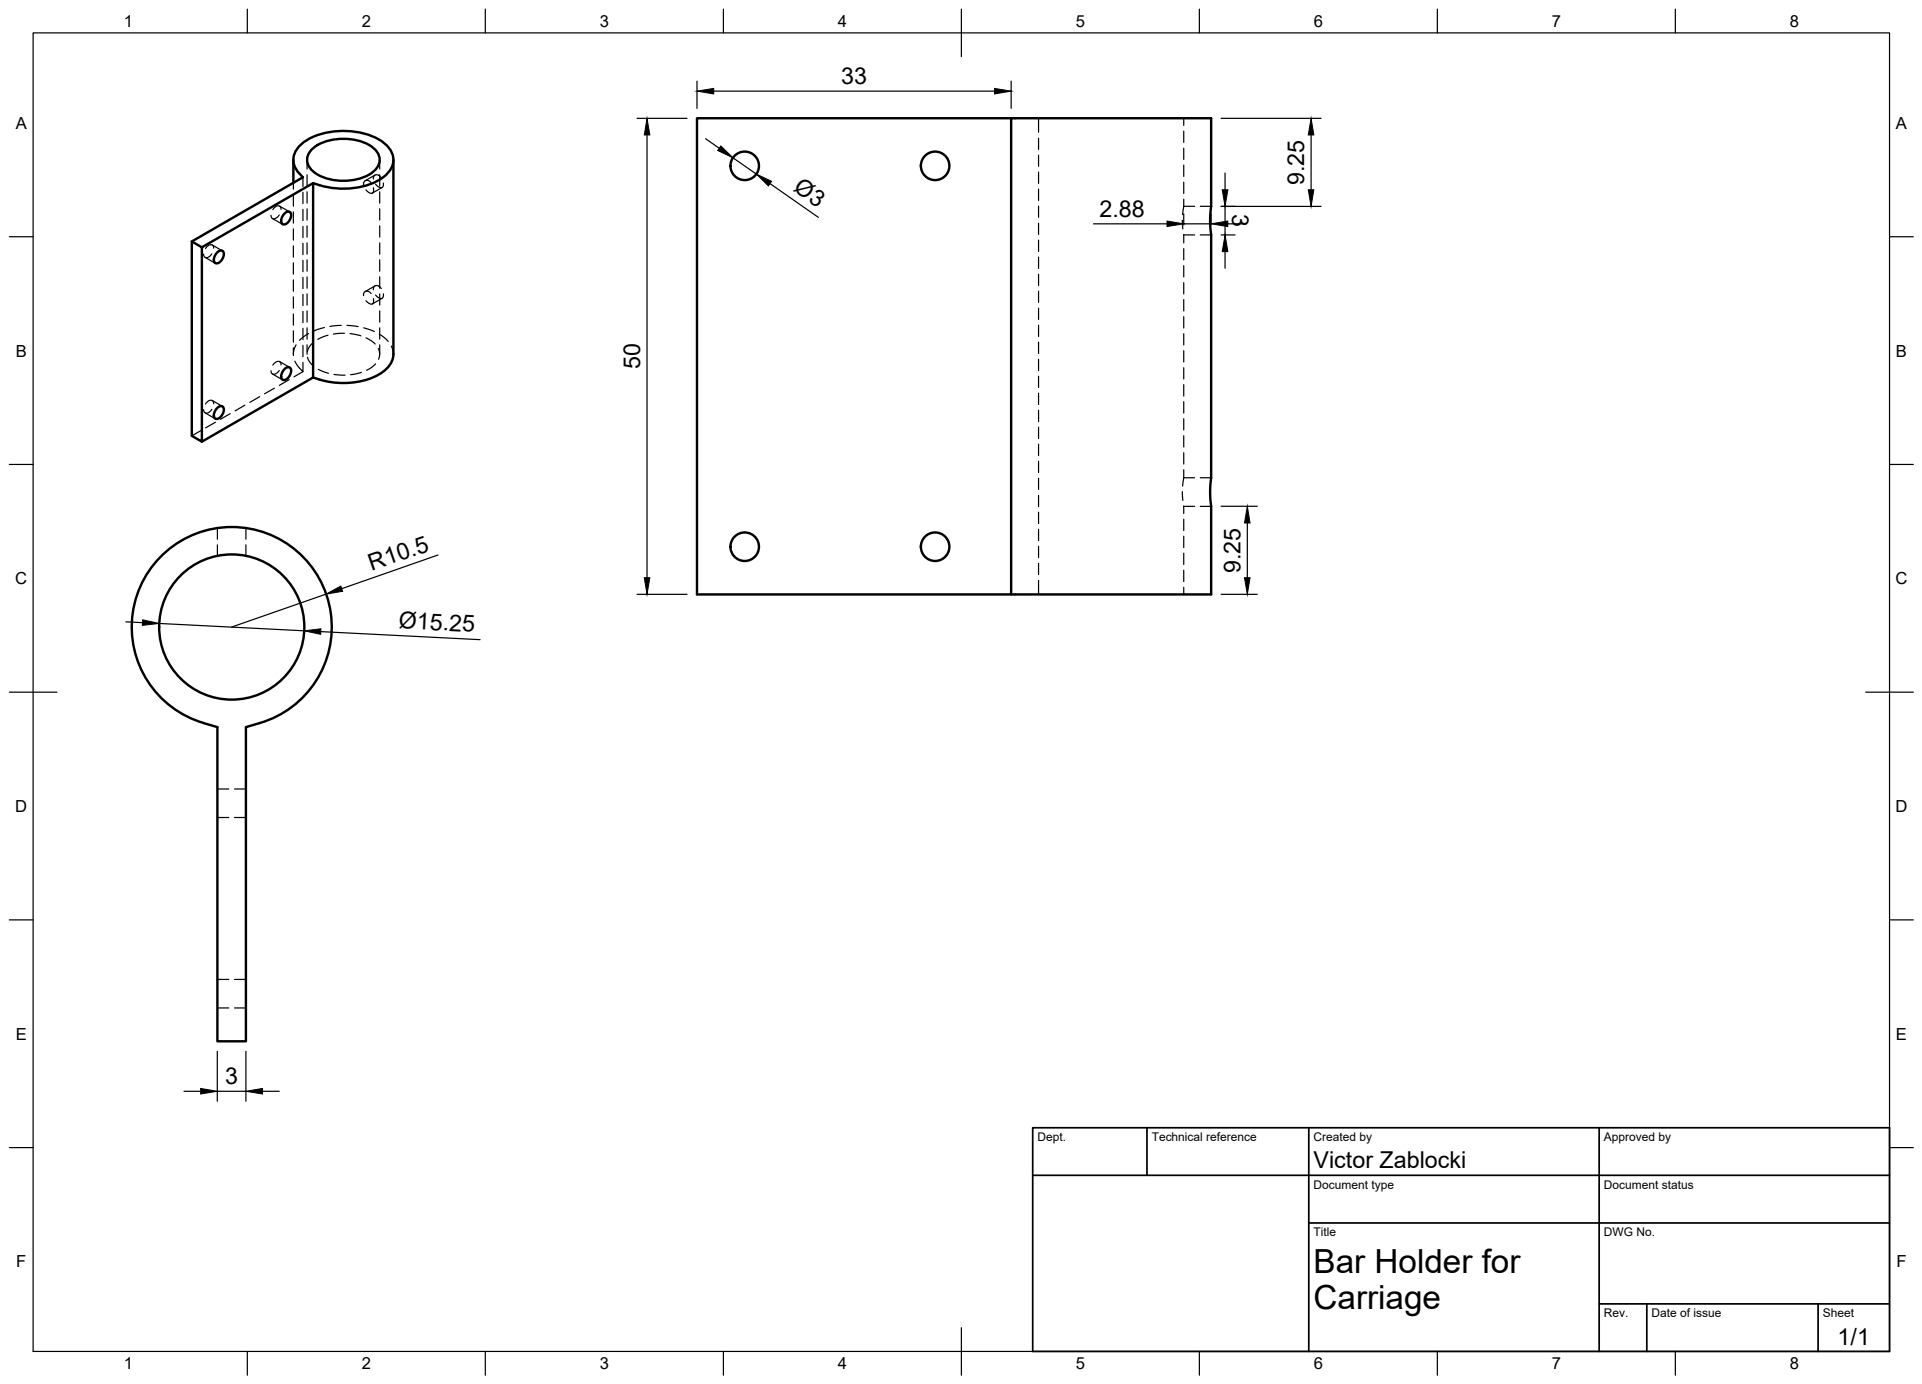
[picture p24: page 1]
Title; DWG No.; Rev.; Date of issue; Sheet

Dept. | Technical reference | Created by Victor Zablocki | Approved by

Document type | Document status

Bar Holder for
Carriage

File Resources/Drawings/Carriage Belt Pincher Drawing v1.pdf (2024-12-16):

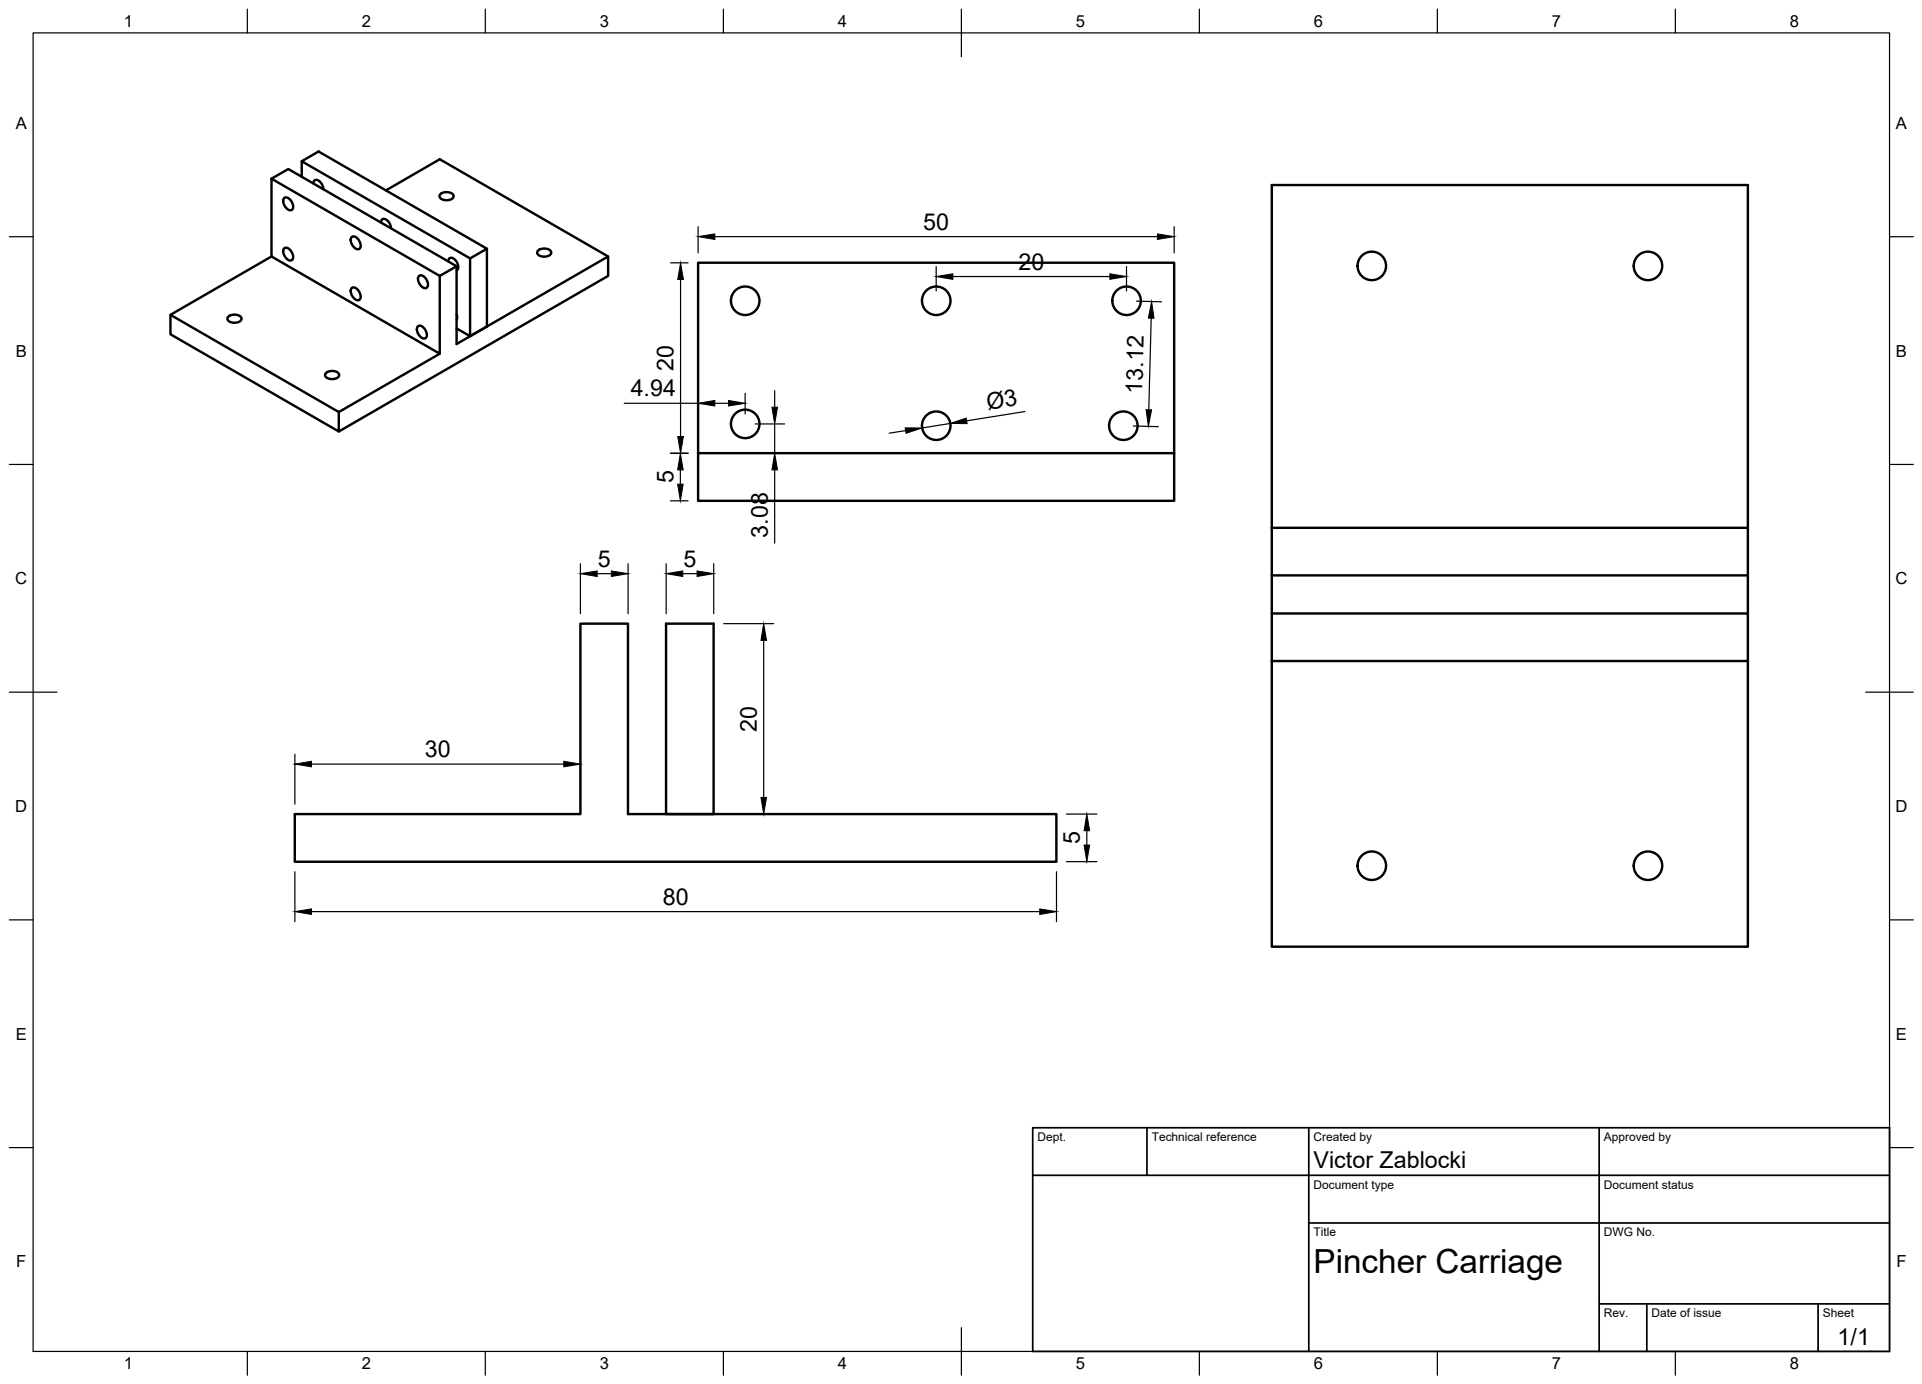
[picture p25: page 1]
Title; DWG No.; Rev.; Date of issue; Sheet; Pincher Carriage

Dept. | Technical reference | Created by Victor Zablocki | Approved by

Document type | Document status

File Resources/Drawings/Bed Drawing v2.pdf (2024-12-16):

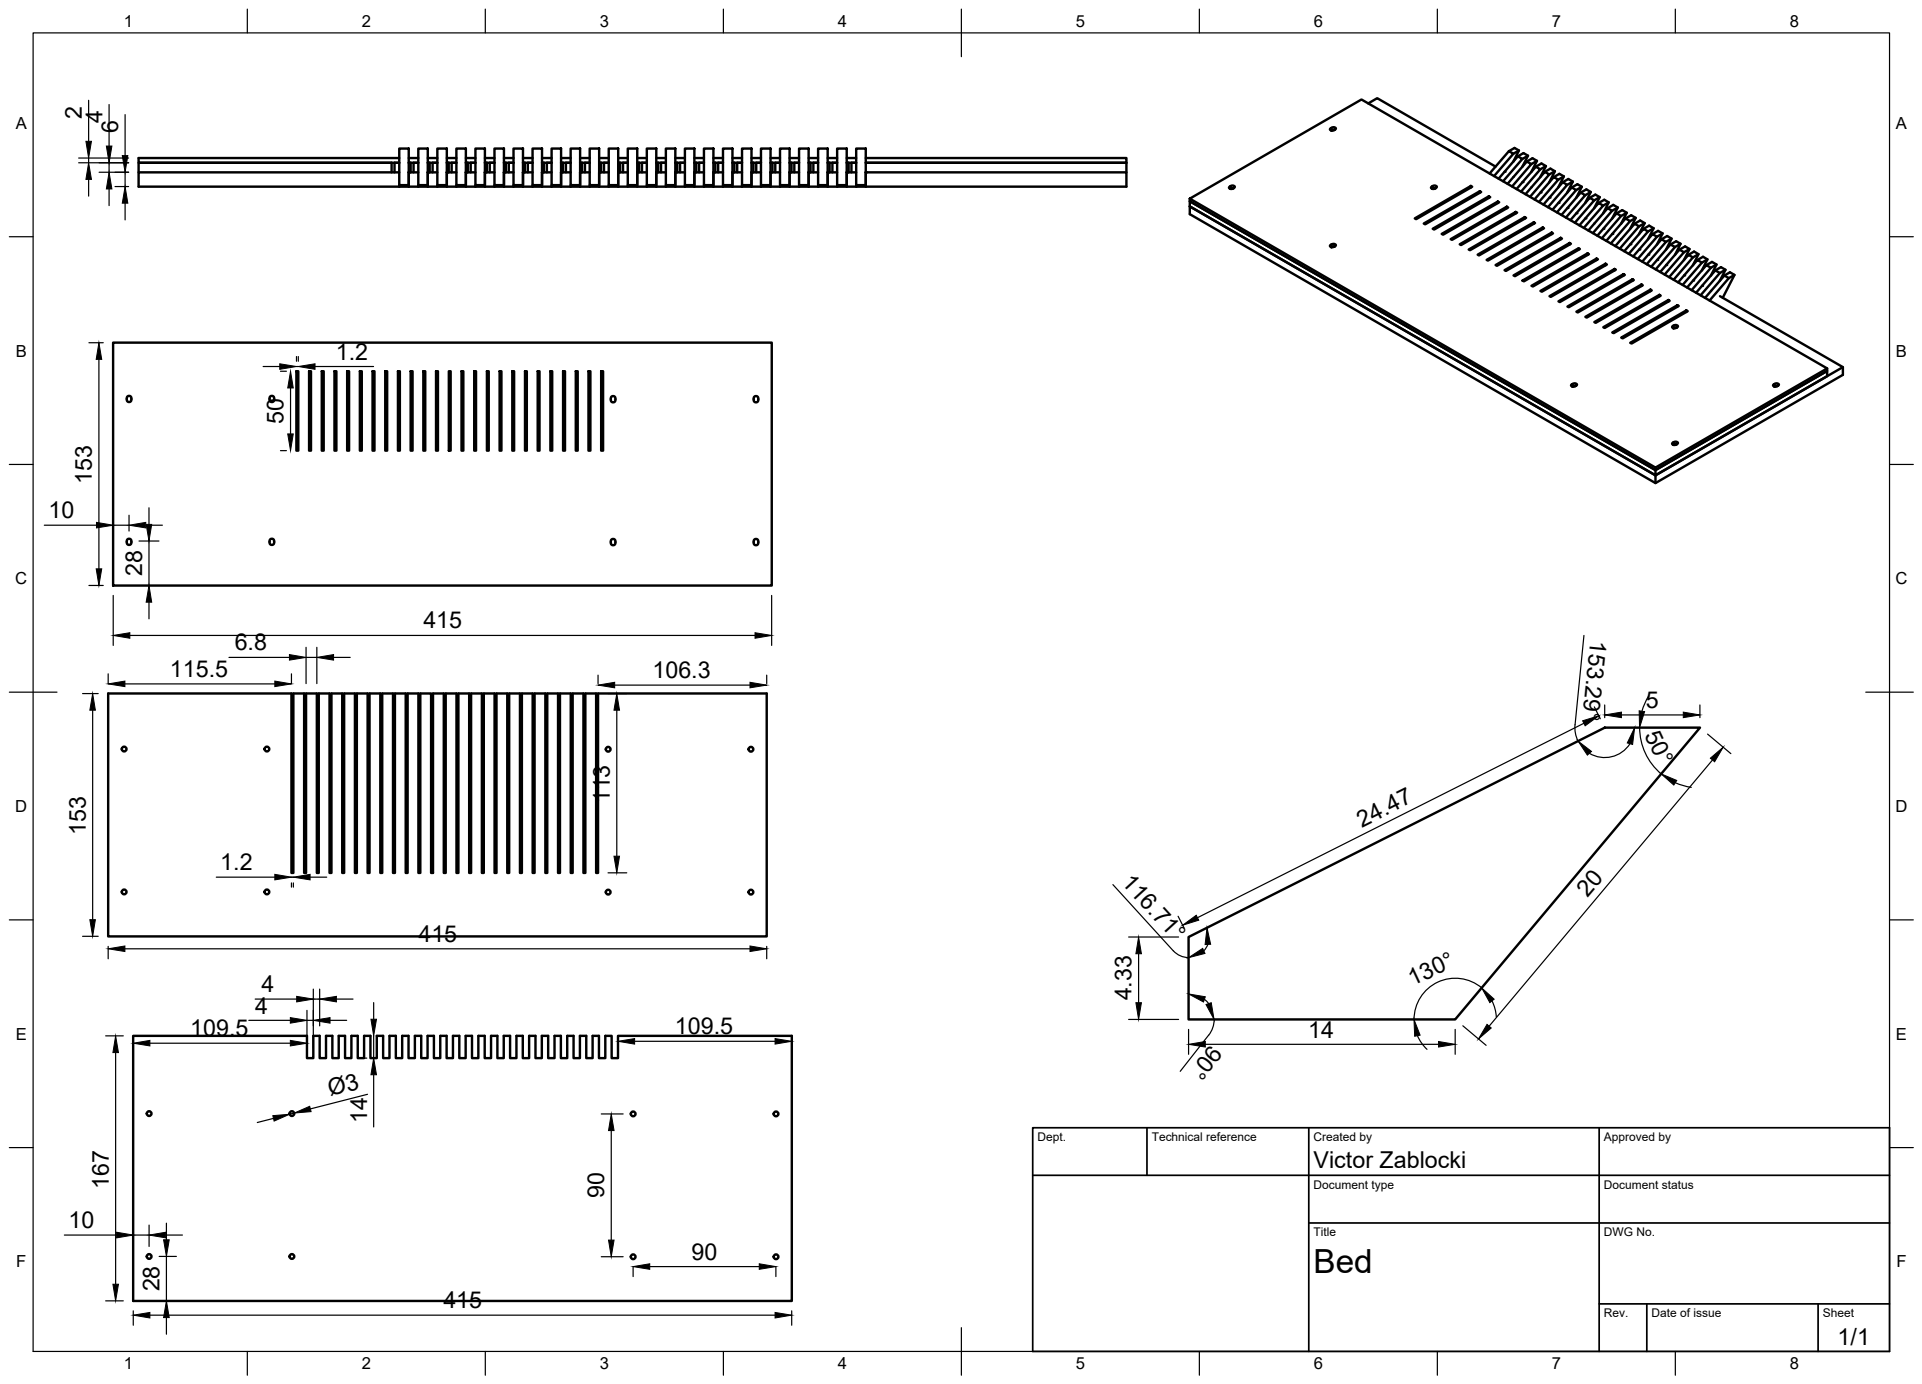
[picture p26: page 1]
8 BCDEF; ABCDEF; Title; DWG No.; Rev.; Date of issue; Sheet; Victor Zablocki 624 153

Dept. | Technical reference | Created by | Approved by

Document type | Document status

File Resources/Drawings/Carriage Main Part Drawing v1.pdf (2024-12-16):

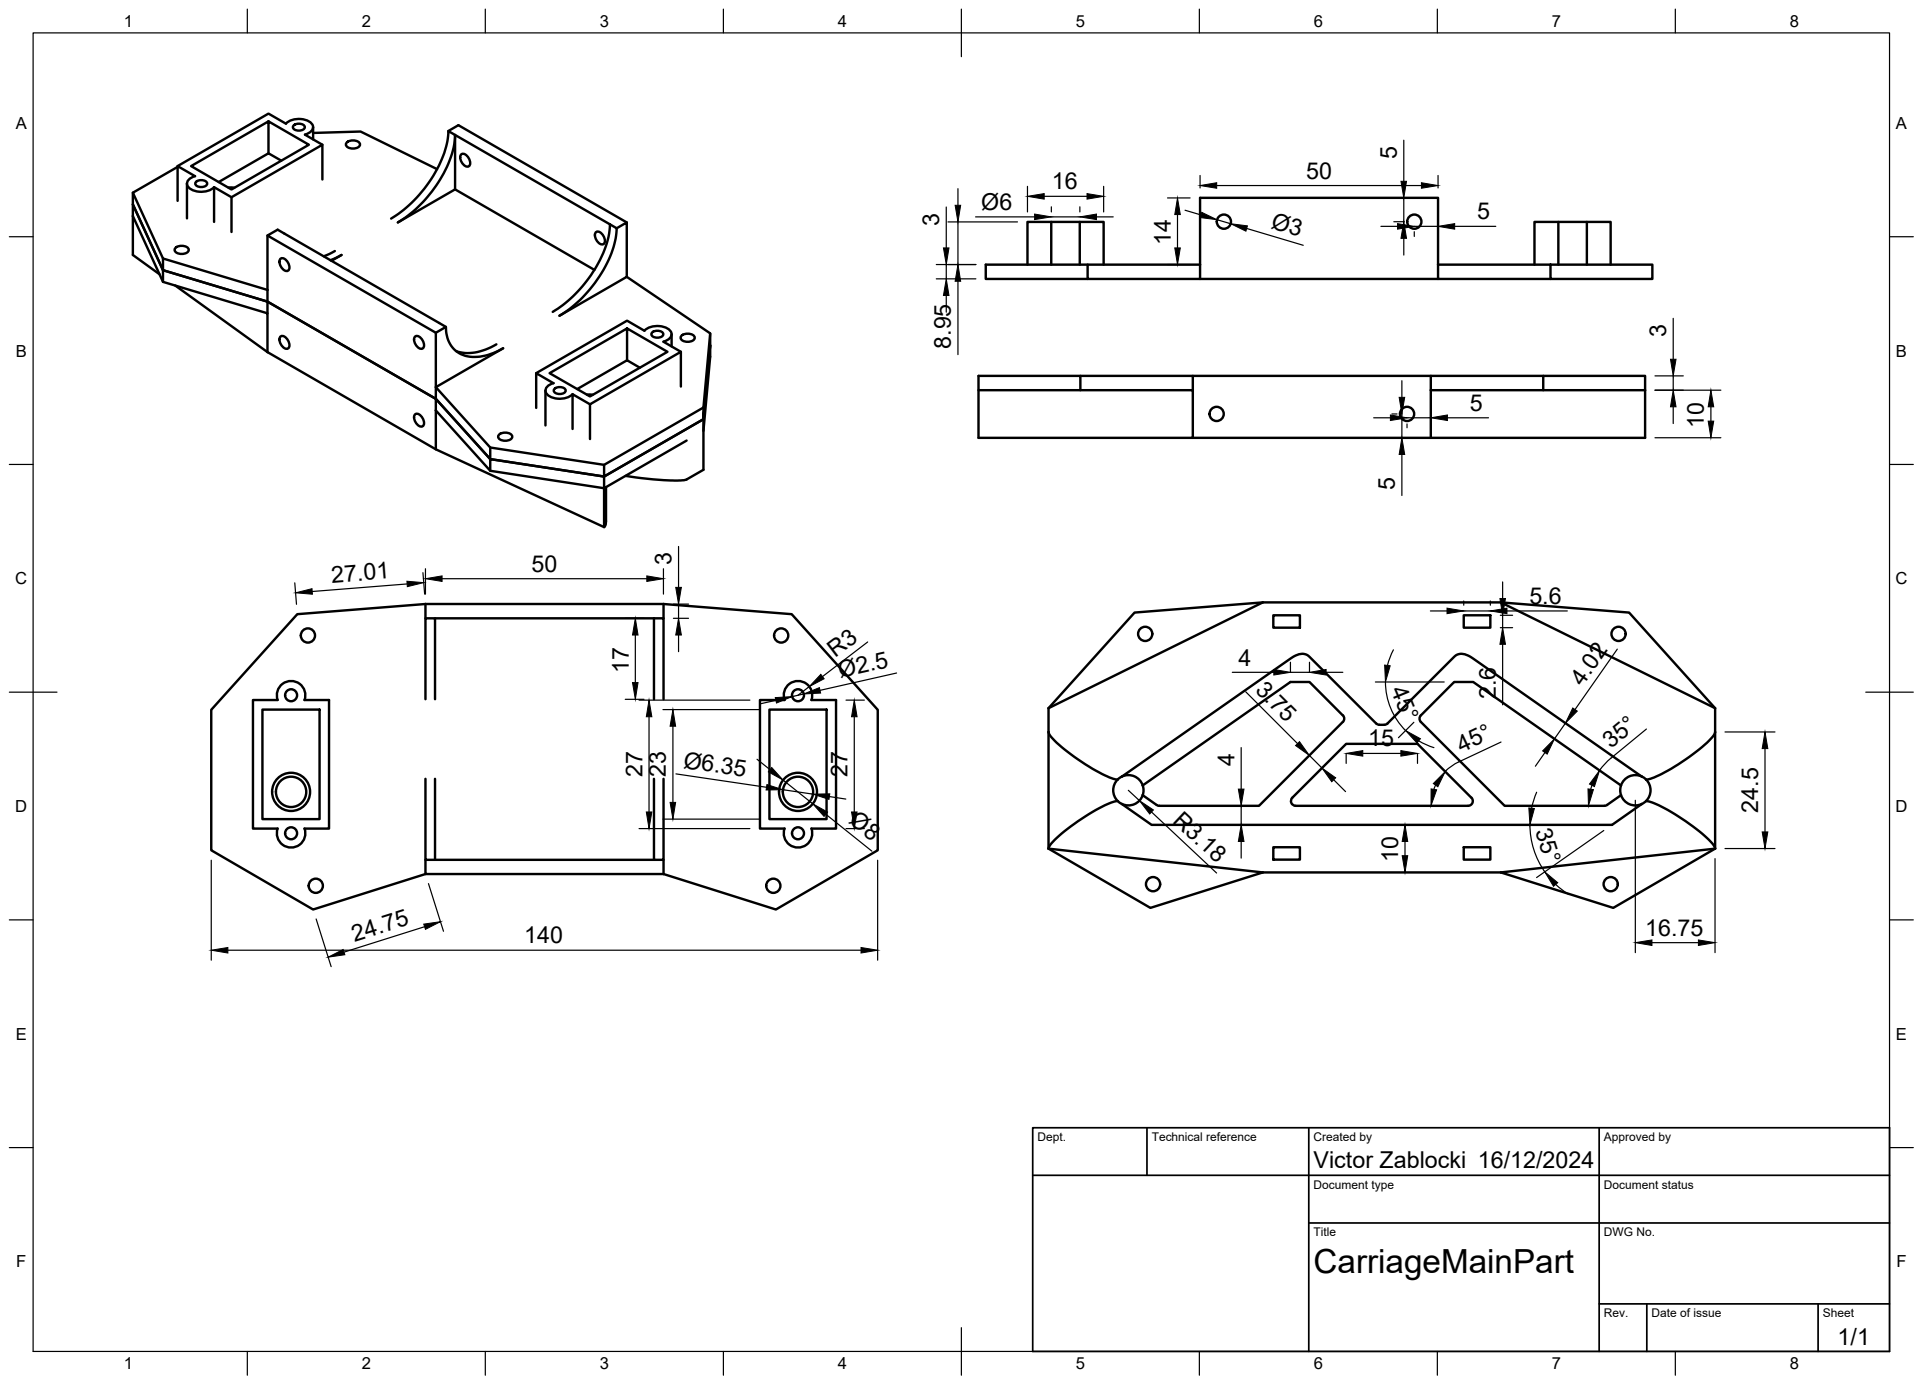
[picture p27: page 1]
Title; DWG No.; Rev.; Date of issue; Sheet

Dept. | Technical reference | Created by Victor Zablocki 16/12/2024 | Approved by

Document type | Document status

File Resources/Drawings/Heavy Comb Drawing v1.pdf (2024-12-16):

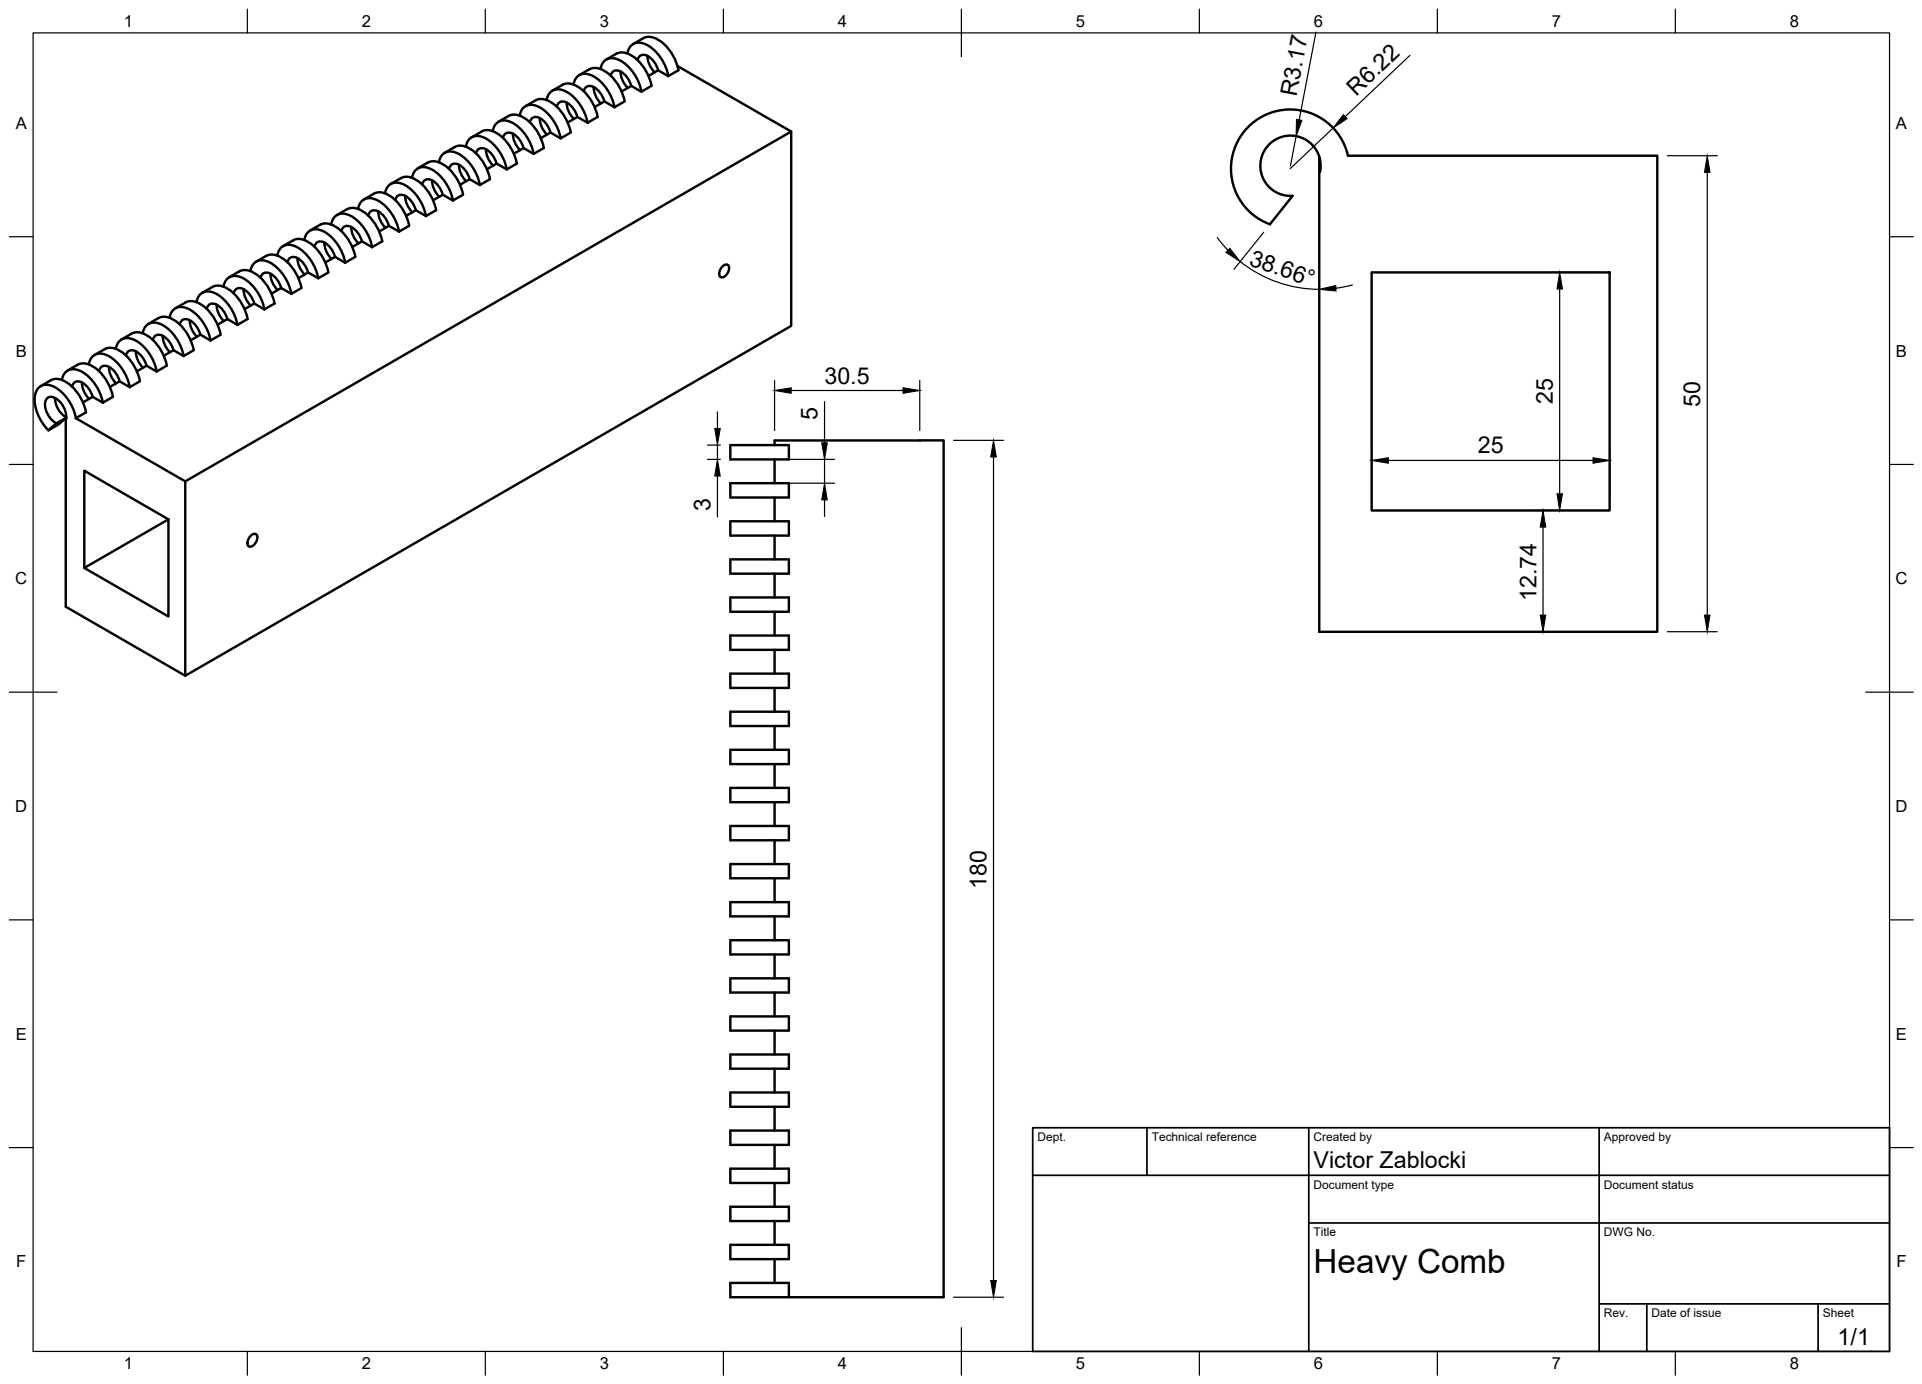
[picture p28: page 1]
Title; DWG No.; Rev.; Date of issue; Sheet; Heavy Comb; Victor Zablocki 180

Dept. | Technical reference | Created by | Approved by

Document type | Document status

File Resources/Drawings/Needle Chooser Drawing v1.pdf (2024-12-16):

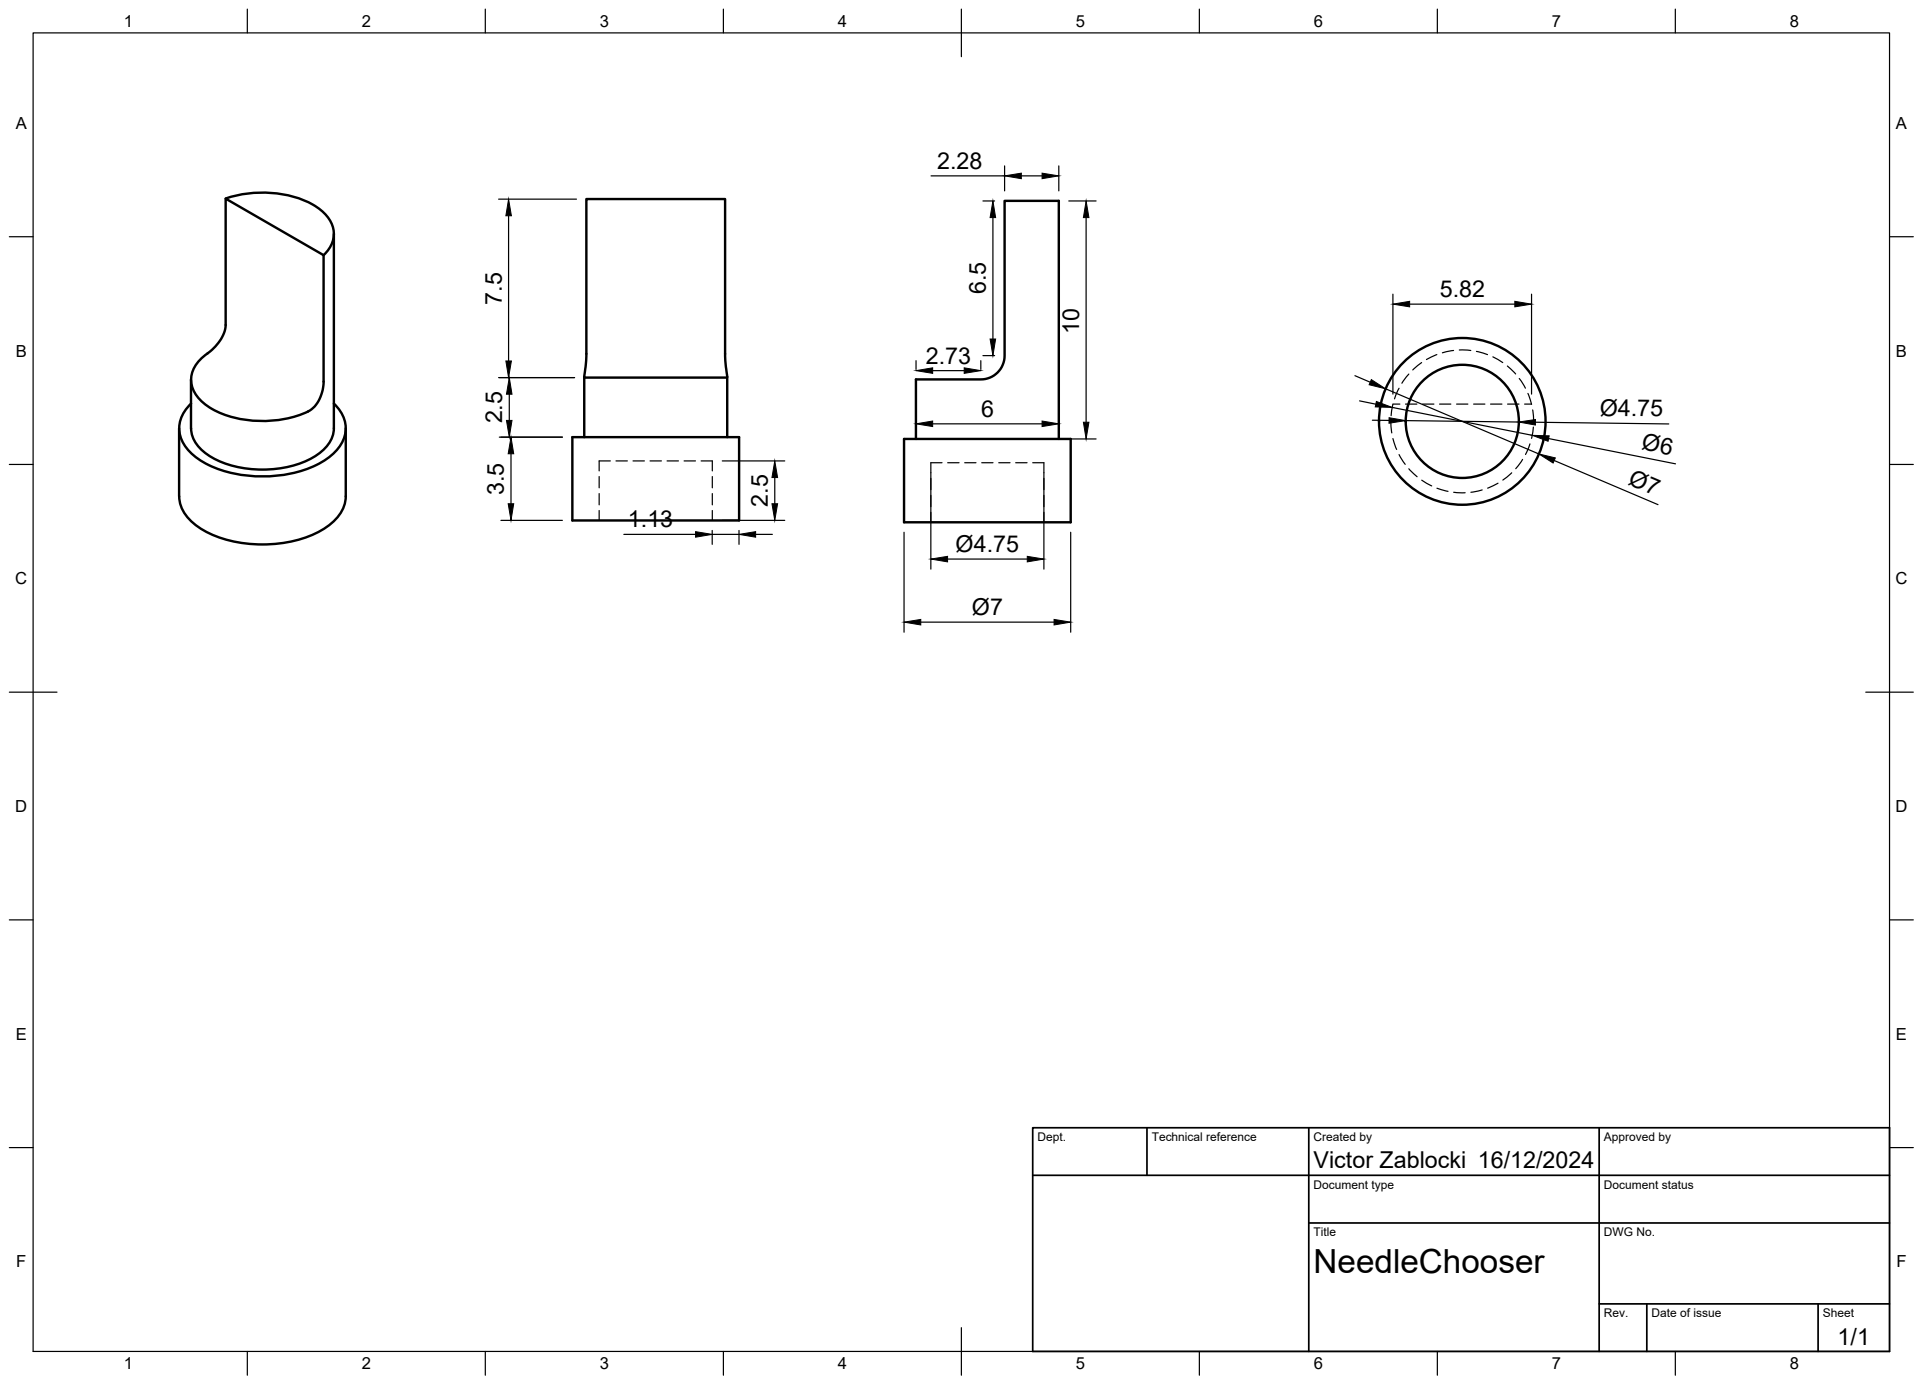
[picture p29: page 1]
Title; DWG No.; Rev.; Date of issue; Sheet; Victor Zablocki 7.5 2.5 3.5

Dept. | Technical reference | Created by 16/12/2024 | Approved by

Document type | Document status

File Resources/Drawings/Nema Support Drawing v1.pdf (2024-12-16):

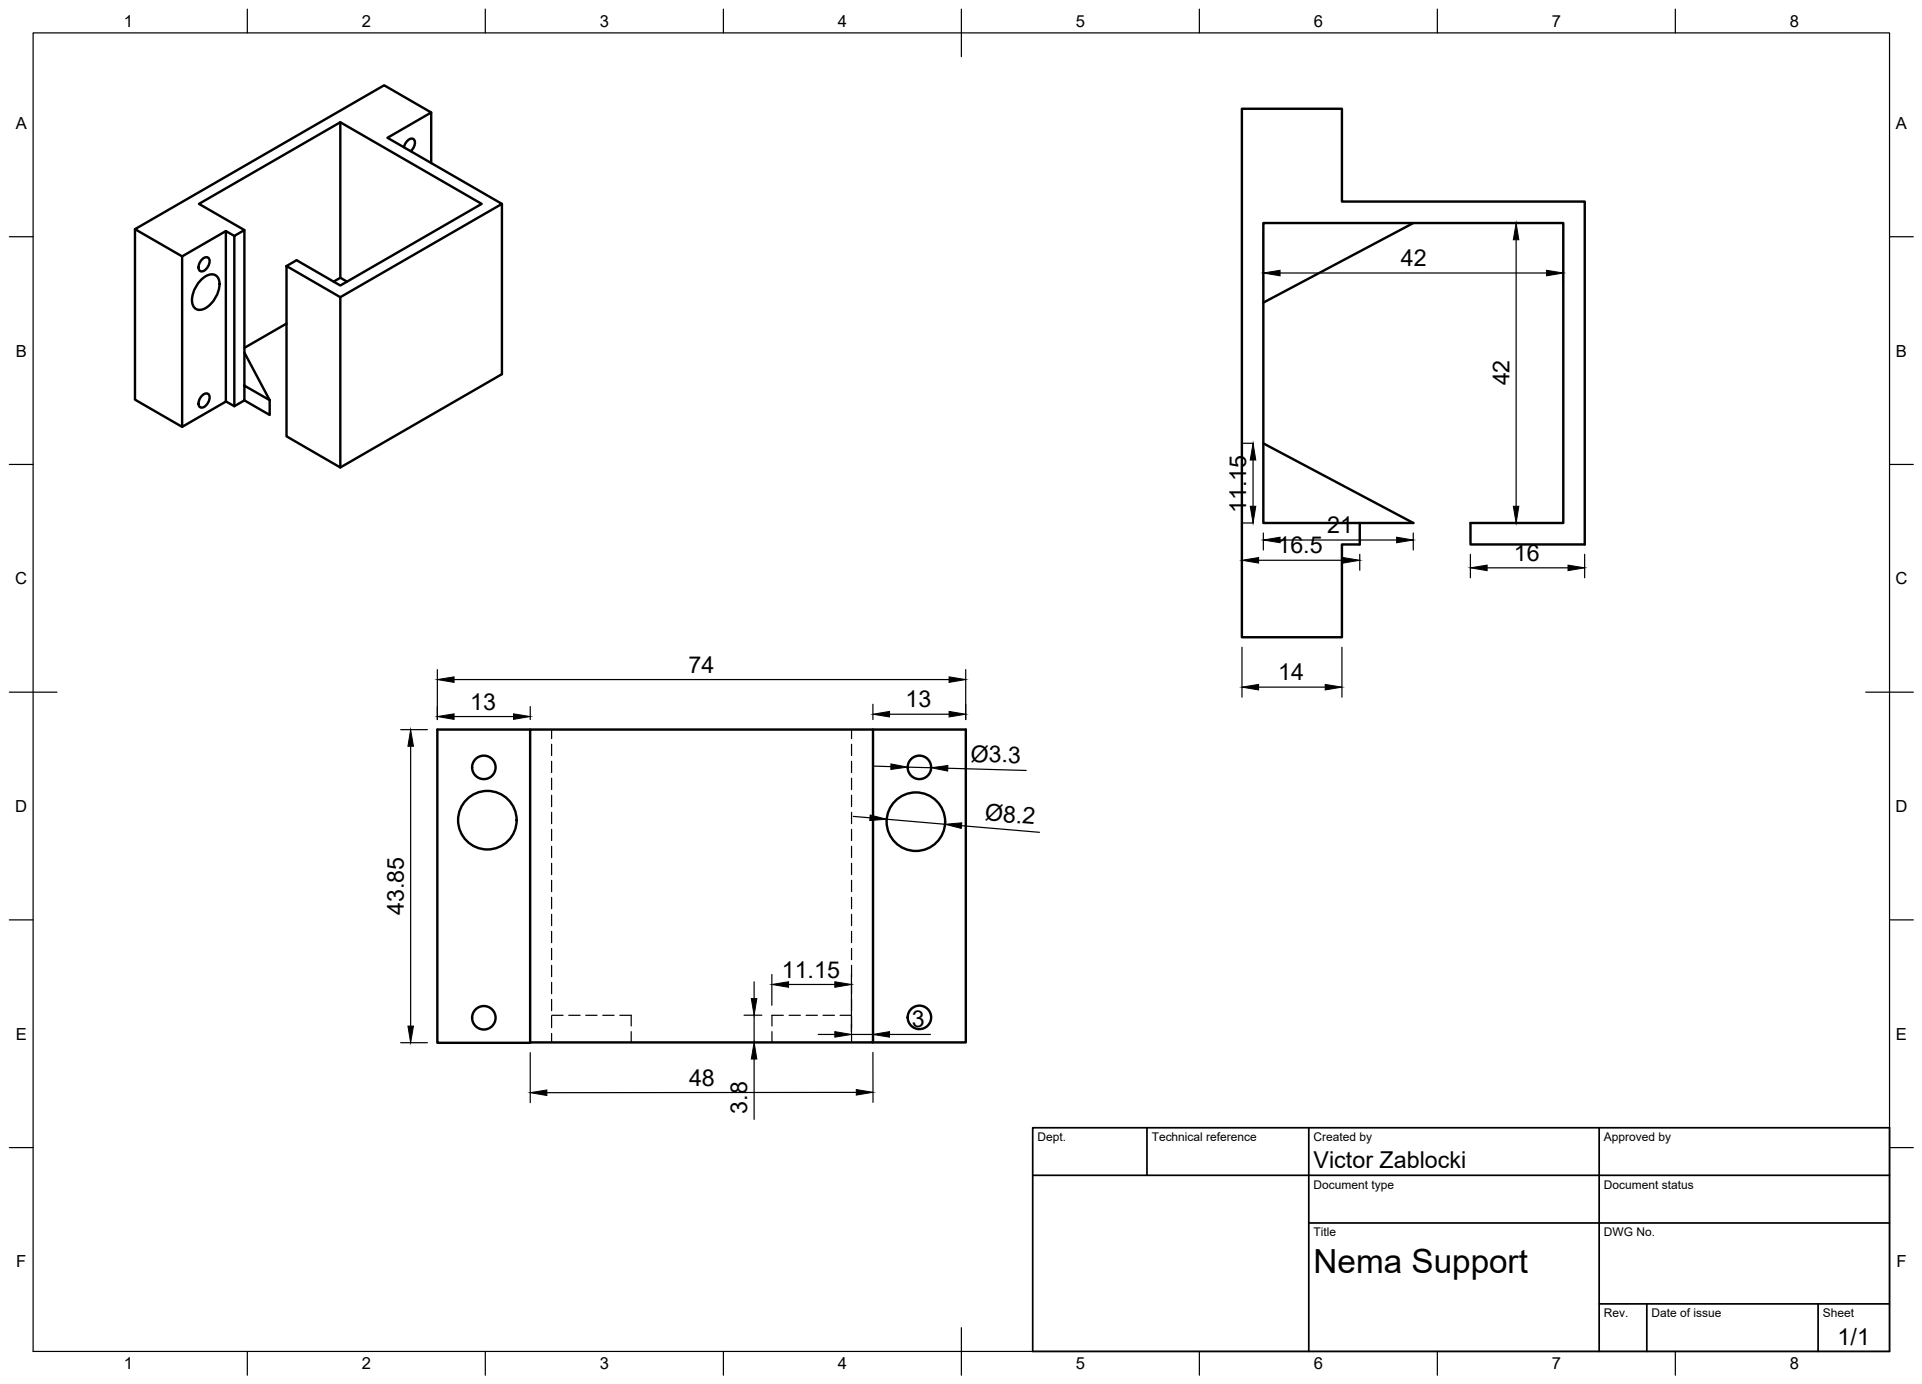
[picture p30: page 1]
Title; DWG No.; Rev.; Date of issue; Sheet; Nema Support

Dept. | Technical reference | Created by Victor Zablocki | Approved by

Document type | Document status

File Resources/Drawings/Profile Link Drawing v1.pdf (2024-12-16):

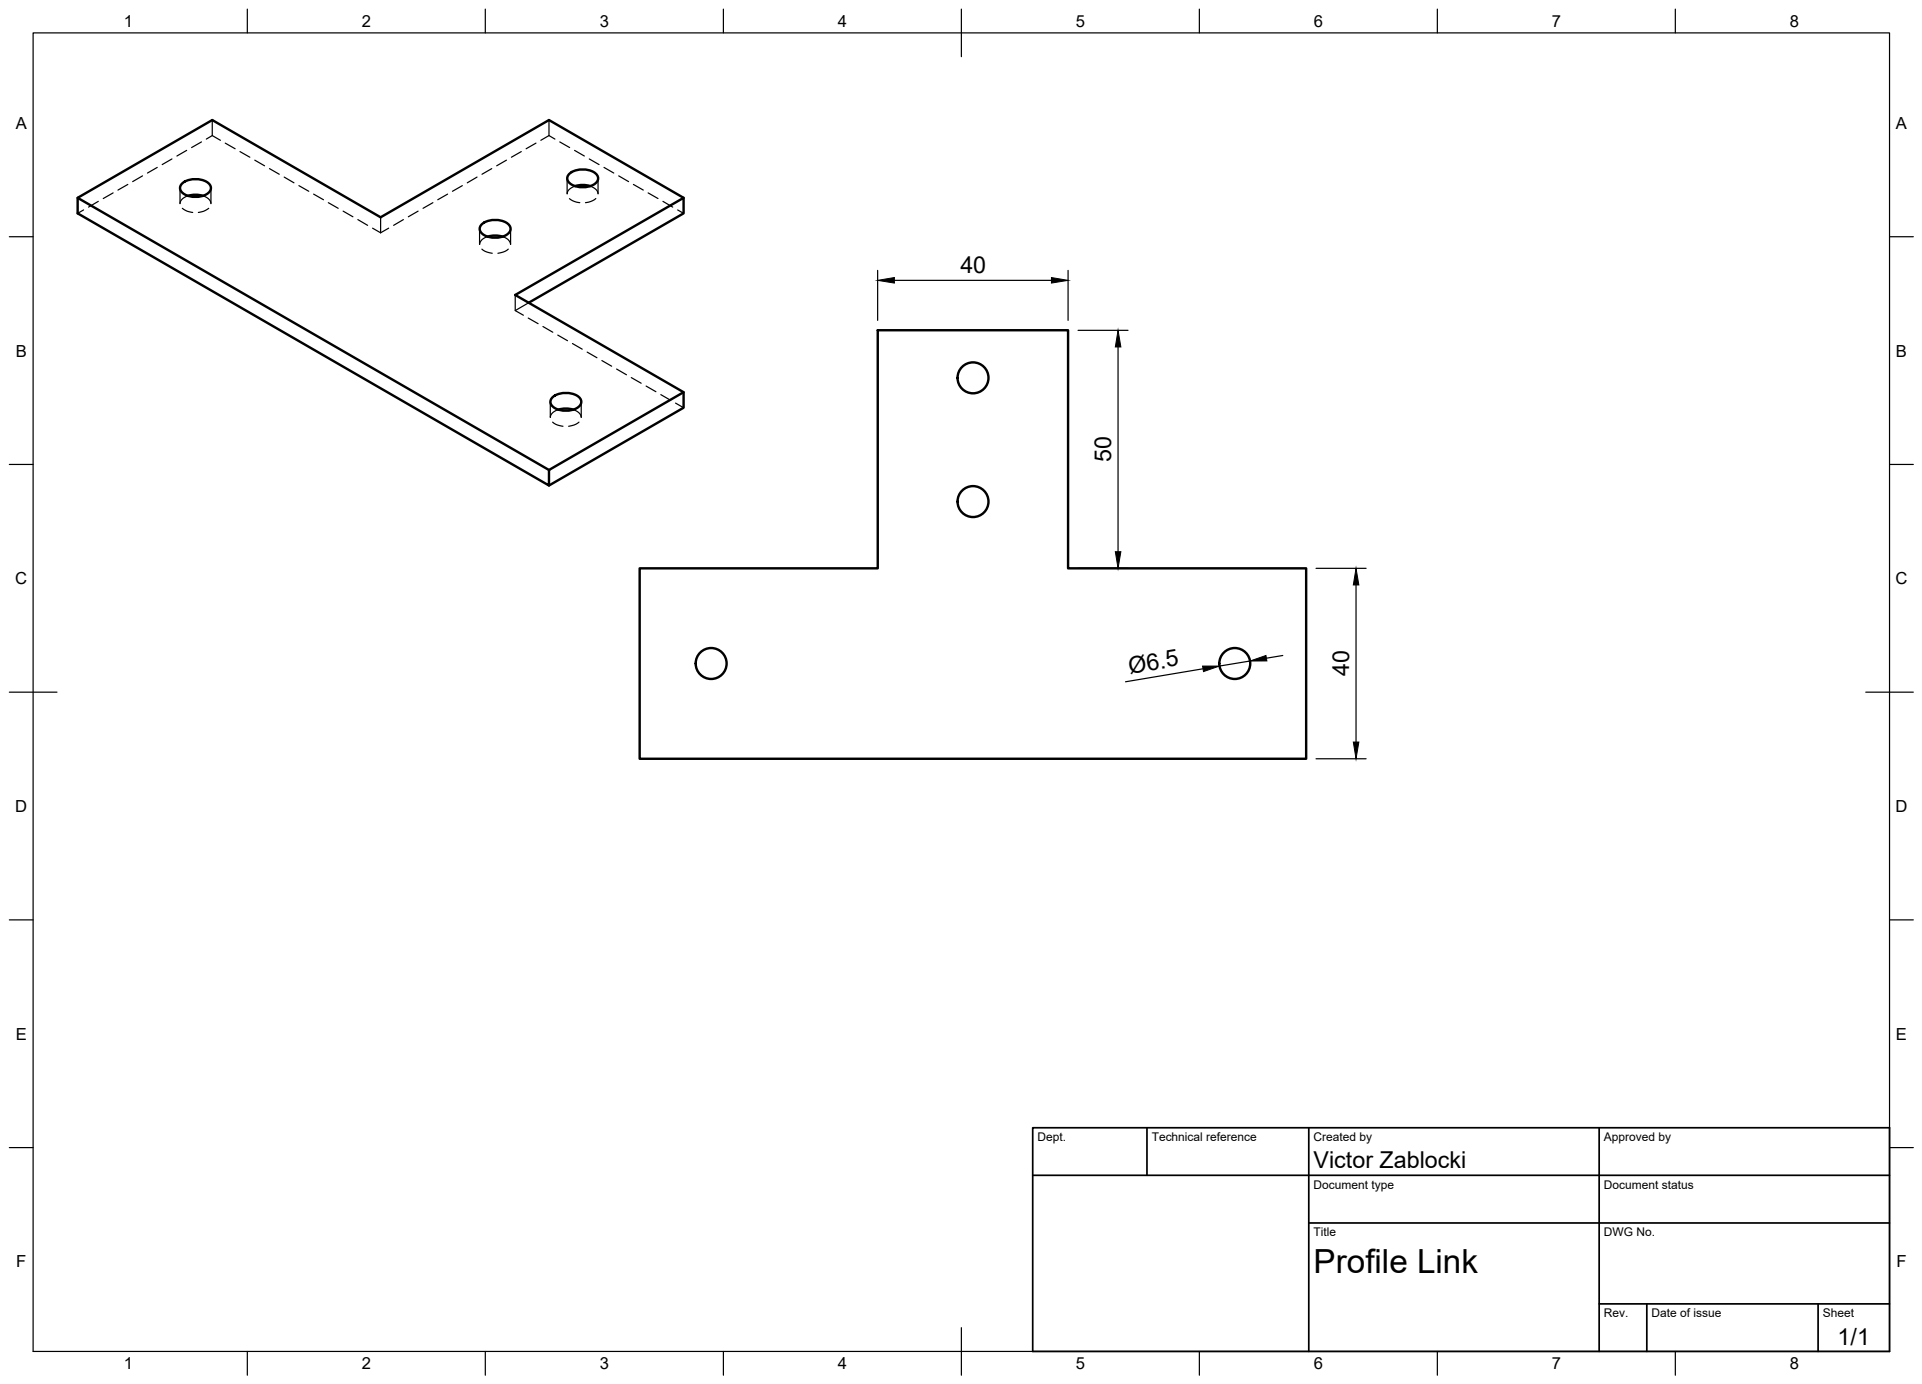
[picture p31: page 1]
Title; DWG No.; Rev.; Date of issue; Sheet; Profile Link; Victor Zablocki 40 50

Dept. | Technical reference | Created by | Approved by

Document type | Document status

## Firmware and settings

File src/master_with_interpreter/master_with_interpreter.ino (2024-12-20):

/*
 * Knitting Machine Control Code
 * 
 * Supported Commands:
 * - l         : Move small servos to the left.
 * - r         : Move small servos to the right.
 * - s x       : Move the big servo to position x (0–180).
 * - s1 x      : Move small servo 1 to position x (0–180).
 * - s2 x      : Move small servo 2 to position x (0–180).
 * - n x       : Move NEMA motors by x steps (positive for forward, negative for reverse).
 * - krb       : Knit a full row to the right (basic).
 * - klb       : Knit a full row to the left (basic).
 * - krs       : Knit a full row to the right (switch, wait for confirmation).
 * - kls       : Knit a full row to the left (switch, wait for confirmation).
 * - krp       : Knit a full row to the right (pattern, wait for confirmation).
 * - klp       : Knit a full row to the left (pattern, wait for confirmation).
 * - fl        : Move to the first needle on the left from the switch point.
 * - fr        : Move to the first needle on the right from the switch point.
 * - al        : Move after the first needle left (continue from the last step to the end).
 * - ar        : Move after the first needle right (continue from the last step to the end).
 * - lt x      : Take x needles to the left (raise needles up).
 * - rt x      : Take x needles to the right (raise needles up).
 * - ls x      : Skip x needles to the left (lower needles down).
 * - rs x      : Skip x needles to the right (lower needles down).
 * - knit x    : Knit x rows (right and left together count as one row).
 * - knits x   : Knit x rows (step, wait for confirmation after each row).
 * - knitp x   : Knit x rows (pause, wait for confirmation after each row).
 *
 */

#include <Wire.h>
#include <Servo.h>
#include <LiquidCrystal.h>

#define servo1_pin 9 
#define servo2_pin 10 
#define servo_big_pin 11
#define COMM_RECEIVE_PIN 7

#define MAX_BUFFER_SIZE 50
#define MAX_COMMAND_LENGTH 10

const int CONF_RECEIVE_PIN = 8; //Additional switch pin

LiquidCrystal lcd(13, 12, 5, 4, 3, 2);

//Values to be valibrated
const int servo1_left_take = 140;   // Position for taking left needles with servo 1
const int servo2_left_take = 160;   // Position for taking left needles with servo 2
const int servo1_right_take = 25;    // Position for taking right needles with servo 1
const int servo2_right_take = 60;   // Position for taking right needles with servo 2


const int servo1_left_skip = 170;   // Position for skipping left needles with servo 1
const int servo2_left_skip = 10;    // Position for skipping left needles with servo 2
const int servo1_right_skip = 170;  // Position for skipping right needles with servo 1
const int servo2_right_skip = 10;   // Position for skipping right needles with servo 2

const int servo_big_left = 70;      // Position for big servo when moving to the left
const int servo_big_right = 1;      // Position for big servo when moving to the right

const int first_needle_distance_left = 250;  // Distance to the first needle on the left (measured from switch, after bump)
const int first_needle_distance_right = 250; // Distance to the first needle on the right (measured from switch,  after bump)

const int carriage_steps = 2500;   // Number of steps required to move the entire carriage
const int needle_steps = 40;       // Number of steps needed per needle 

const int delay_big_servo = 1000;  // Delay for big servo movement (longer movement)
const int delay_small_servo = 500; // Delay for small servo movement (shorter movement)
const int delay_sending = 500;      // Delay for sending commands to NEMA motor (for communication pin switch)


//Declaration of other components
Servo servo1;     
Servo servo2;
Servo servoBig;

//Declaration of the buffer
struct CommandBuffer {
    char commands[MAX_BUFFER_SIZE][MAX_COMMAND_LENGTH];
    int head;
    int tail;
    int count;
} cmdBuffer;

/**
 * Initializes the command buffer to manage incoming commands for processing.
 * Resets the buffer head, tail, and count values.
 */
void initCommandBuffer() {
    cmdBuffer.head = 0;
    cmdBuffer.tail = 0;
    cmdBuffer.count = 0;
}

/**
 * Checks if the command buffer is full.
 * @return true if the buffer is full, false otherwise.
 */
bool isBufferFull() {
    return cmdBuffer.count >= MAX_BUFFER_SIZE;
}

/**
 * Checks if the command buffer is empty.
 * @return true if the buffer is empty, false otherwise.
 */
bool isBufferEmpty() {
    return cmdBuffer.count == 0;
}

/**
 * Adds a command string to the command buffer if there's space.
 * @param command The command string to add.
 * @return true if the command was added successfully, false otherwise.
 */
bool addToBuffer(String command) {
    if (isBufferFull() || command.length() >= MAX_COMMAND_LENGTH) {
        Serial.println("Buffer full or command too long");
        return false;
    }
    
    command.toCharArray(cmdBuffer.commands[cmdBuffer.tail], MAX_COMMAND_LENGTH);
    cmdBuffer.tail = (cmdBuffer.tail + 1) % MAX_BUFFER_SIZE;
    cmdBuffer.count++;
    
    Serial.print("Command added to buffer: ");
    Serial.println(command);
    Serial.print("Buffer count: ");
    Serial.println(cmdBuffer.count);
    
    return true;
}

/**
 * Displays a message on the LCD.
 * This function clears the existing display and prints new text.
 * @param line1 The first line of text to display. This is mandatory.
 * @param line2 The second line of text to display. This is optional and defaults to an empty string if not provided.
 */
void displayMessage(String line1, String line2 = "") {
  lcd.clear();                   
  lcd.setCursor(0, 0);          
  lcd.print(line1);               
  lcd.setCursor(0, 1);            
  lcd.print(line2);               

}


/**
 * Sets up hardware pins, initializes servos, and prepares the system.
 * Called once during the microcontroller's boot process.
 */
void setup() {
    pinMode(servo1_pin, OUTPUT);  
    pinMode(servo2_pin, OUTPUT);  
    pinMode(COMM_RECEIVE_PIN, INPUT);

    pinMode(CONF_RECEIVE_PIN, INPUT_PULLUP);
    
    Serial.begin(9600);           
    Wire.begin();              
    
    servo1.attach(servo1_pin); 
    servo2.attach(servo2_pin); 
    servoBig.attach(servo_big_pin, 900, 2200);
    
    servo1.write(0);
    servo2.write(0); 
    
    initCommandBuffer();


    lcd.begin(16, 2);
    displayMessage("Welcome to", "Stitchify");

    
    Serial.println("Knitting machine controller ready.");
}

/**
 * Waits for confirmation from the CONF_RECEIVE_PIN before proceeding.
 * Used during specific knitting operations requiring acknowledgment.
 * Checking serial while waiting.
 * @return true once confirmation is received.
 */
void waitForRowConfirmation() {
  displayMessage("Is everything", "okay?");
  int switch_state = digitalRead(CONF_RECEIVE_PIN);
  while(switch_state == LOW) {
    switch_state = digitalRead(CONF_RECEIVE_PIN);
  }
}

/**
 * Moves components based on the given input command string.
 * Handles movement of servos and NEMA motors.
 * Checking serial while moving NEMA.
 * @param input The command string containing the movement instructions.
 */
void moveStep(String input)
{
  if (input.startsWith("l")) {
    servo1.write(servo1_left_take);     
    servo2.write(servo2_left_take);        
    Serial.print("Servos moved left");
    delay(delay_small_servo);

  }else if (input.startsWith("r")) {
    servo1.write(servo1_right_take);     
    servo2.write(servo2_right_take);        
    Serial.print("Servos moved right");
    delay(delay_small_servo);

  }else if (input.startsWith("s ")) {
    int angle = input.substring(2).toInt();
    servoBig.write(angle);     
    Serial.print("Big servo moved");
    delay(delay_big_servo);

  }else if (input.startsWith("s1 ")) {
    int angle = input.substring(3).toInt();
    if (angle > 180) angle = 180;   
    servo1.write(angle);         
    Serial.print("Servo1 moved to: ");
    Serial.println(angle);
    delay(delay_small_servo);

  } else if (input.startsWith("s2 ")) {

    int angle = input.substring(3).toInt();
    if (angle > 180) angle = 180;
    servo2.write(angle); 
    Serial.print("Servo2 moved to: ");
    Serial.println(angle);
    delay(delay_small_servo);

  } else if (input.startsWith("n ")) {
    int nema_angle = input.substring(2).toInt();
    int neg = 0;
    if (nema_angle < 0) 
    {
      nema_angle = -nema_angle;
      neg = 1;
    }
    int bit_high = nema_angle >> 8;
    int bit_low = nema_angle & 255;


    Serial.print("Sending to NEMA motor: ");
    Serial.println(neg);
    Serial.println((bit_high << 8) + bit_low);

    Wire.beginTransmission(8);
    Wire.write(neg); 
    Wire.write(bit_high); 
    Wire.write(bit_low);
    Wire.endTransmission();


    delay(delay_sending);
    while (digitalRead(COMM_RECEIVE_PIN) == LOW) {
    }
    Serial.println("Signal received from slave");

  } 
  else {

    Serial.println("Invalid command. Use 's1 x', 's2 x', or 'n x'.");
  }
}

/**
 * Moves the knitting machine to the first needle on the right side (so that it's up).
 */
void goFirstRight()
{
  moveStep("r");
  moveStep("s "+String(servo_big_left));
  moveStep("n "+String(first_needle_distance_right));
  moveStep("s "+String(servo_big_right));
}

/**
 * Moves the knitting machine to the first needle on the left side (so that it's up).
 */
void goFirstLeft()
{
  moveStep("l");
  moveStep("s "+String(servo_big_right));
  moveStep("n -"+String(first_needle_distance_left));
  moveStep("s "+String(servo_big_left));
}

/**
 * Executes a row movement command based on the input.
 * Handles knitting rows and needle adjustments.
 * @param input The row command string.
 */
void moveRow(String input)
{
  Serial.println(input);
  if (input.startsWith("krb")) {
    goFirstRight();
    waitForRowConfirmation();
    moveStep("n "+String(carriage_steps));
  }
  else if(input.startsWith("klb")) {
    goFirstLeft();
    waitForRowConfirmation();
    moveStep("n -"+String(carriage_steps));
  }
  else if (input.startsWith("krs")) {
    goFirstRight();
    waitForRowConfirmation();
    moveStep("n "+String(carriage_steps));
  }
  else if(input.startsWith("kls")) {
    goFirstLeft();
    waitForRowConfirmation();
    moveStep("n -"+String(carriage_steps));
  }
  else if (input.startsWith("krp")) {
    goFirstRight();
    waitForRowConfirmation();
    moveStep("n "+String(carriage_steps));
  }
  else if(input.startsWith("klp")) {
    goFirstLeft();
    waitForRowConfirmation();
    moveStep("n -"+String(carriage_steps));
  }
  else if(input.startsWith("fl")) {
    goFirstLeft();
  }
  else if(input.startsWith("fr")) {
    goFirstRight();
  }
  else if(input.startsWith("ar")) {
    moveStep("n "+String(first_needle_distance_left));
  }
  else if(input.startsWith("al")) {
    moveStep("n -"+String(first_needle_distance_right));
  }
  else if(input.startsWith("lt ")) {
    int n_needles = input.substring(4).toInt();
    moveStep("s1 "+String(servo1_left_take));     
    moveStep("s2 "+String(servo2_left_take));   
    moveStep("n -"+String(needle_steps * n_needles));

  }
  else if(input.startsWith("ls ")) {
    int n_needles = input.substring(4).toInt();
    moveStep("s1 "+String(servo1_left_skip));     
    moveStep("s2 "+String(servo2_left_skip));   
    moveStep("n -"+ String(needle_steps * n_needles));

  }
  else if(input.startsWith("rt ")) {
    int n_needles = input.substring(4).toInt();
    moveStep("s1 "+String(servo1_right_take));     
    moveStep("s2 "+String(servo2_right_take));   
    moveStep("n "+String(needle_steps * n_needles));

  }
  else if(input.startsWith("rs ")) {
    int n_needles = input.substring(4).toInt();
    moveStep("s1 "+String(servo1_right_skip));     
    moveStep("s2 "+String(servo2_right_skip));   
    moveStep("n "+String(needle_steps * n_needles));
  }
  else
  {
    moveStep(input);
  }
}


/**
 * Processes knitting commands, including multiple rows and patterns.
 * @param input The knitting command string.
 */
void knit(String input)
{
  if (input.startsWith("knit ")) {
    int number_rows = input.substring(5).toInt();
    displayMessage("Ready to knit:", String(number_rows) + " rows");
    delay(2000);
    for(int i=0; i<number_rows; i++)
    {
      if(i%2==0) moveRow("klb");
      if(i%2==1) moveRow("krb");
      displayMessage("Knitted " + String(i + 1), "/" + String(number_rows) + " rows");
      delay(1000);
    }
    displayMessage("Knitting done!");
  }
  else if (input.startsWith("knits ")) {
    int number_rows = input.substring(6).toInt();
    displayMessage("Ready to knit:", String(number_rows) + " rows");
    delay(2000);
    for(int i=0; i<number_rows; i++)
    {
      if(i%2==0) moveRow("kls");
      if(i%2==1) moveRow("krs");
      displayMessage("Knitted " + String(i + 1), "/" + String(number_rows) + " rows");
      delay(1000);
    }
    displayMessage("Knitting done!");
  }
  else if (input.startsWith("knitp ")) {
    int number_rows = input.substring(6).toInt();
    displayMessage("Ready to knit:", String(number_rows) + " rows");
    delay(2000);
    for(int i=0; i<number_rows; i++)
    {
      if(i%2==0) moveRow("klp");
      if(i%2==1) moveRow("krp");
      displayMessage("Knitted " + String(i + 1), "/" + String(number_rows) + " rows");
      delay(1000);
    }
    displayMessage("Knitting done!");
  }
  else
  {
    moveRow(input);
    displayMessage("Knitting done!");
  }
}

/**
 * Retrieves the next command from the buffer.
 * @return The next command string, or an empty string if the buffer is empty.
 */
String getNextCommand() {
  if (isBufferEmpty()) {
      return "";
  }
  String command = String(cmdBuffer.commands[cmdBuffer.head]);
  cmdBuffer.head = (cmdBuffer.head + 1) % MAX_BUFFER_SIZE;
  cmdBuffer.count--;
  return command;
}

/**
 * Processes buffered commands, executing them in sequence.
 */
void processBufferedCommands() {
  if (!isBufferEmpty()) {
    String command = getNextCommand();
    if (command.length() > 0) {
      knit(command);
    }
  }
}

/**
 * Reads serial input for incoming commands and adds them to the buffer.
 * Supports parsing multiple commands separated by semicolons.
 */
void checkSerial()
{
  if (Serial.available() > 0) {
    String input = Serial.readStringUntil('\n');
    input.trim();
    int start_index = 0;
    int semicolon_index;
    do{
      semicolon_index = input.indexOf(';', start_index);
      String command;
      if(semicolon_index == -1) 
      {
        command = input.substring(start_index);
      } 
      else 
      {
        command = input.substring(start_index, semicolon_index);
        start_index = semicolon_index + 1;
      }
      command.trim();
      if(command.length() > 0) 
      {
        addToBuffer(command);
      }
            
    }while(semicolon_index != -1);
  }
}

/**
 * Main loop function, repeatedly called during the program's execution.
 * Handles serial input and processes buffered commands.
 */
void loop() {
  checkSerial();
  processBufferedCommands();
}

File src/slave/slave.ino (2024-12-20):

#include <Wire.h>

// Pin definitions
#define step_pin 2           // Step pin for motor driver
#define dir_pin  5           // Direction pin for motor driver
#define comm_send_pin 11     // Communication pin to signal master device

// Switch pins for detecting end positions
const int switch_pin_right = 12;
const int switch_pin_left = 13;

// Expected positions for calibration
const int expected_pos_left = 0;
const int expected_pos_right = 0;

// Variables to track motor state and movement
int current_pos = 0, target_steps = 0, steps_pos_neg = 0;

/**
 * @brief Initializes hardware, I2C communication, and prints initial switch states for debugging.
 */
void setup() 
{
  pinMode(step_pin, OUTPUT);
  pinMode(dir_pin, OUTPUT);

  pinMode(switch_pin_right, INPUT_PULLUP);
  pinMode(switch_pin_left, INPUT_PULLUP);

  pinMode(comm_send_pin, OUTPUT);
  digitalWrite(comm_send_pin, LOW);

  Wire.begin(8);
  Wire.onReceive(receive_data);

  Serial.begin(9600);
  Serial.println("Ready to receive step count.");

  int switch_state_right = digitalRead(switch_pin_right);
  int switch_state_left = digitalRead(switch_pin_left);
  Serial.println(switch_state_right);
  Serial.println(switch_state_left);
}

/**
 * @brief Main loop, currently unused.
 */
void loop() 
{
}

/**
 * @brief Sends a signal to the master device via the communication pin.
 */
void send_signal_to_master() {
  digitalWrite(comm_send_pin, HIGH);
}

/**
 * @brief Callback function to handle data received via I2C. Parses the step count and direction.
 * 
 * @param byte_count Number of bytes received via I2C.
 */
void receive_data(int byte_count) 
{
  digitalWrite(comm_send_pin, LOW);

  int neg = 0, steps = 0;

  neg = Wire.read();
  steps = Wire.read();
  steps = (steps << 8) + Wire.read();

  Serial.print("Received steps: ");
  Serial.println(steps);
  Serial.println(neg);

  target_steps = steps;
  move_motor(neg, target_steps);
}

/**
 * @brief Moves the motor slightly backward when switch activation.
 * 
 * @param neg Direction flag: 0 for forward, 1 for reverse.
 */
void back_up(int neg)
{
  if (neg == 0) 
  {
    digitalWrite(dir_pin, LOW); 
  } 
  else 
  {
    digitalWrite(dir_pin, HIGH); 
  }

  for (int j = 0; j < 45; j++)
  { 
    current_pos -= steps_pos_neg; 
    digitalWrite(step_pin, HIGH);
    delay(500);
    digitalWrite(step_pin, LOW);
    delay(500);
  }
}

/**
 * @brief Moves the motor a specified number of steps in the given direction while monitoring switch states.
 * 
 * @param neg Direction flag: 0 for forward, 1 for reverse.
 * @param steps Number of steps to move.
 */
void move_motor(int neg, int steps) {
  steps_pos_neg = neg == 1 ? -1 : 1;

  if (steps == 0) 
  {
    return;
  }
  else if (neg == 0) 
  {
    digitalWrite(dir_pin, HIGH); 
  } 
  else 
  {
    digitalWrite(dir_pin, LOW); 
  }

  bool switch_pressed_as_expected = 1;

  for (int i = 0; i < steps; i++) {
    int switch_state_right = digitalRead(switch_pin_right);
    int switch_state_left = digitalRead(switch_pin_left);

    if (switch_state_right == HIGH || switch_state_left == HIGH) {

      if (switch_state_right == HIGH && abs(current_pos - expected_pos_right) > 2) 
      {
        switch_pressed_as_expected = 0;
      }
      if (switch_state_left == HIGH && abs(current_pos != expected_pos_left) > 2) 
      {
        switch_pressed_as_expected = 0;
      }

      back_up(neg);
      break;
    }

    current_pos += steps_pos_neg;
    digitalWrite(step_pin, HIGH);
    delay(700);
    digitalWrite(step_pin, LOW);
    delay(700);
  }

  // Option to send a signal only if switches behaved as expected
  /*
  if (switch_pressed_as_expected) 
  {
    send_signal_to_master();
  }
  */

  // Notify the master device of movement completion
  send_signal_to_master();

  Serial.print("Motor moved by: ");
  Serial.println(steps);
  Serial.print("Motor at Pos: ");
  Serial.println(current_pos);
}

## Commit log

2024-11-05 created project folders and initial electronic fritzing file
    [electronic_sketch.fzz]
2024-11-05 added first sketch of 3D assembly
2024-11-05 finished wiring steppers, servos and switches
    [electronic_sketch.fzz]
2024-11-05 rewired pretty
    [electronic_sketch.fzz]
2024-11-05 Uploading the laser cutting dxf files
    [OverBed v1.dxf, Triangle Base v1.dxf, UnderBed v1.dxf]
2024-11-06 added connection between esp32 and arduino uno, changed switch wiring to separate them
    [electronic_sketch.fzz]
2024-11-11 added new Wemos d1 r32
    [electronic_sketch.fzz]
2024-11-12 added correct switches
    [electronic_sketch.fzz]
2024-11-13 added 16-channel servo controller
    [electronic_sketch_with_WeMos.fzz]
2024-11-13 Wired switches directly on cnc shield, added connection between WeMos and Arduino/cnc shield
    [electronic_sketch_with_WeMos.fzz]
2024-11-18 Repository cleanup
    [OverBed v1.dxf, Triangle Base v1.dxf, UnderBed v1.dxf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]
2024-11-18 Update Sender.ino
    Changing the sender to servo
2024-11-18 Update Receiver_arduino.ino
    Receiver updated to use I2C communication and control for the nema
2024-11-19 Update Sender.ino
    Added second servo
2024-11-19 Update Receiver_arduino.ino
    Added switch for security
2024-11-19 Update Receiver_arduino.ino
    Changed pin for switch
2024-11-20 Organizing the repository
    [Bed Holder.stl, OverBed v1.dxf, Overbed v2.dxf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]
2024-11-25 Create switch_z-
    Seperate code to test switch.
    Initial problem: wrong wiring. The switches had the cables soldered wrongly. FIXED
2024-11-25 Update Receiver_arduino.ino
    Working version, without switch
2024-11-25 Receiver_arduino.ino
    Trying to incorporate the switch. TRY 1
2024-11-25 Update Receiver_arduino.ino
    Switch working. Issue: wrong position, since the calculation doesn't incorporate switch.
2024-11-25 Update Receiver_arduino.ino
    Since we cannot send more than a byte by I2C, changing moving to posistion x, to moving by x steps.
2024-11-25 Update Receiver_arduino.ino
    New version, moving x steps. Incorporated switches. Counter works.
2024-11-26 Create file_to_arduino.py
    Initial interpreter for the file. It sends necessary input to Arduino. Tu be used with master code with interpreter.
2024-11-26 Rename switch_z- to switch_z-.ino
    More intuitive file naming.
2024-11-27 Update slave.ino
    Pin 2 was used twice. I have not removed the previous switch tries, which made the code bug. Additionaly print taking a lot of time causes delay, since commented out.
    [slave.ino]
2024-11-27 Update file_sending_to_arduino.py
    Delay was too small. We also have additional comman at the beginning that needed to be add.
    [file_sending_to_arduino.py]
2024-11-27 Working negative steps for stepper
2024-12-03 Added two switches into the code that will stop the NEMA once activated, also added some documentation in the slave program
    [Cotes.dxf, Triangular_Base_linkage_bars.dxf]
2024-12-03 l/r feature and incorporation of big servo
2024-12-04 added precise servo angles, skip first needle, goes back and forth with right angles, stops once hits the switches
    [master_with_interpreter.ino, slave.ino]
2024-12-13 added commands knit left/knit right as well as knit n rows (the version created earlier was not compatible with the code as a whole)
    [master_with_interpreter.ino]
2024-12-16 Added the Global Assembly as a step file
2024-12-16 Slave giving back feedback to master. That way if any problem occures we may kill the program.
    [master_with_interpreter.ino, slave.ino]
2024-12-17 Updated fritzing sketch
    [electronic_sketch.fzz]
2024-12-17 added commants to get to first needle as well as skip any needle
    [master_with_interpreter.ino]
2024-12-17 added expected amount of skipped/taken needels, hence now one can send ort x
    [master_with_interpreter.ino]
2024-12-17 added right values and calibration
2024-12-17 correct values for steps between needles and servos
    [master_with_interpreter.ino]
2024-12-17 Added check if the switches are pressed at the expected position
2024-12-17 Fritzing s^ketch with lcd screen
    [electronic_sketch.fzz]
2024-12-18 Wire management with the LCD screen in Fritzing
    [electronic_sketch.fzz]
2024-12-18 Adding all the stl files
    [ALU_Linkage.stl, BarHolder.stl, CarriageMainPart.stl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]
2024-12-19 Added control switch for the user
2024-12-20 lcd screen and new values for servos
2024-12-20 added a new version of the electronic sketch on fritzing with the wemos and lcd screen
    [electronic_sketch_with_WeMos.fzz, newest_electronic_sketch_lcd_wemos.fzz]
